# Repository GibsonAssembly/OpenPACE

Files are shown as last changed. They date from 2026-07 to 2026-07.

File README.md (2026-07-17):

# OpenPACE

Code, STL and Gerber files for EvoFlow and EvoSampler, together with the companion software repositories included as submodules.

## Repository layout

| Path | Contents |
|---|---|
| `EvoFlow` | EvoFlow reactor — STL and Gerber files |
| `EvoSampler` | EvoSampler — code, STL and Gerber files |
| `EvoMonitor` | Real-time monitoring dashboard (EvoHub appliance) — submodule of [Schwank-Lab/evoflow-monitor](https://github.com/Schwank-Lab/evoflow-monitor) |
| `EvoGenotype` | PACE genotype-trajectory analysis CLI — submodule of [Schwank-Lab/evo-genotype](https://github.com/Schwank-Lab/evo-genotype) |
| `Evotool` | Reactor control tool (`evotool.py`) and Pico controller firmware — submodule of [Schwank-Lab/evoflow-reactor](https://github.com/Schwank-Lab/evoflow-reactor) |

## Cloning

`EvoMonitor`, `EvoGenotype` and `Evotool` are git submodules, so clone recursively:

```bash
git clone --recursive https://github.com/GibsonAssembly/OpenPACE.git
```

If you already cloned without `--recursive`, initialise them with:

```bash
git submodule update --init --recursive
```

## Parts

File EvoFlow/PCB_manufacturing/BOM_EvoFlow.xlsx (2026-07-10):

Comment | Description | Designator | Footprint | LibRef | Quantity
LTC1050CS8#TRPBF,C580346 | Ampilfier | AMP1, AMP2 | SOIC127P599X175-8N | LTC1050CS8#TRPBF | 2
VT1E101M0607, C141426 | Capacitor Polarised,100uF, | C1, C2, C3, C4, C5, C6 | CAPAE660X800N | VT1E101M0607 | 6
22µF 25V 0805, C45783 | Capacitor 22µF +/-20% 25V 0805, C45783 | C7, C12 | C0805 | C22uF | 2
4.7uF, C162420 | Chip Capacitor, 4.7 µF,50V | C8, C9, C11, C13, C14, C19, C20, C22, C37, C39 | C0805 | C4.7uF | 10
C15850 | Chip Capacitor, 10uF, 25V, 0805, Thickness 1.45 mm | C10, C17, C18, C29, C30, C33, C34 | C0805 | C10uF | 7
100nF,C307331 | Chip Capacitor, 0402, CL05B104KB54PNC | C15, C16, C27, C28, C31, C32 | RESC1005X55N | C100nF | 6
100nF,C49678 | Chip Capacitor | C21, C23, C25, C26, C35, C36, C38, C40 | C0805 | C100nF | 8
22nF,50V, C1729 | Chip Capacitor | C24, C41, C42 | C0805 | C22nF | 3
S1A, C330217 | Diode, C330217 | D1, D2, D3, D4, D5, D6, D7, D8 | DIOM5026X262N | S1A+ | 8
FAN3224TMX | Gate driver, two channels, low side,C457631 | Driver1, Driver2, Driver3, Driver4, Driver5, Driver6, Driver7 | SOIC127P599X175-8N | FAN3224TMX | 7
RASPBERRY_PI_PICO_W, C7203003 | Raspberry Pie | IC1 | RASPBERRYPIPICOW | RASPBERRY_PI_PICO_W | 1
TMC2208-LA-T | C115944 | IC2, IC3, IC4 | QFN50P500X500X90-29N-D | TMC2208-LA-T | 3
LTE-5208A, No BOM | LED | IR1, IR2 | LTE5208A | LTE-5208A | 2
B2B-XH-A_LF__SN_ | Connector,C158012 | J1, J2, J3, J4, J5, J6, J7, J8 | SHDR2W64P0X250_1X2_740X575X700P | B2B-XH-A_LF__SN_ | 8
B4B-PH-K-S_LF__SN_, C131334 | Connector,C131334 | J9, J10, J11 | SHDR4W50P0X200_1X4_990X450X600P | B4B-PH-K-S_LF__SN_ | 3
LED, C2288 | Blue LED | LED1, LED2, LED3, LED4 | LEDM168X65N | LED | 4
DMN2053UVT-7 | MOSFET (N-Channel),C5248847 | MOS1, MOS2, MOS3, MOS4, MOS5, MOS6, MOS7 | SOT95P280X100-6N | DMN2053UVT-7 | 7
DC-005 2.0 | Connector,C16214 | P1 | DC005 | DC-005 2.0 | 1
IR photodiode, No BOM | Infra red photodiode, LTR-323DB , 2-Pin THD | PD1, PD2 | LTE5208A | Photodiode | 2
LD1117-5.0 | C347230, Fixed voltage regulator, 12V to 5V | PS1 | SOT230P700X190-4N | LD1117-5.0 | 1
C60816, RC0805FR-074K7L | Resistor, 4.7 kOhm | R1, R2, R3 | RESC2012X60N | RC0805FR-074K7L | 3
No BOM | Heater, No BOM | R4, R5, R6, R7, R8, R9 | TO508P305X812X1398-2P | MP915-200-1% | 6
Resistors,0603,360 Ohm | Resistor，C25194 | R10, R11, R12, R13 | RESC1608X55N | R360 | 4
Chip Resistors, 20k | C4184 | R14, R17, R20, R23, R24, R29, R30, R31, R32 | RESC1608X55N | R20k | 9
C17414, Resistor 10k, 0805 | Chip Resistor, 10 kOhm | R18, R19 | RESC2012X60N | R10k | 2
Resistors,0603,150 Ohm, C22808 | Resistor， C22808 | R21, R22 | RESC1608X55N | R150 | 2
K2-1102SP-C4SC-04 | Switch, C127509 | S1, S2, S3, S4, S5, S9, S10 | K2-1102SP-C4SC-04 | K2-1102SP-C4SC-04 | 7
C54949, DSIC02LSGET | 2 channel Switch | S6, S7, S8 | SOP254P930X445-4N | DSIC02LSGET | 3
DS18B20+,No BOM | Integrated Circuit, No BOM | TM1, TM2, TM3 | DS18B20 | DS18B20+ | 3
TC33X-2-203E | Variable Resistor，C720648 | VR1, VR2, VR3 | TC33X2503E | TC33X-2-203E | 3

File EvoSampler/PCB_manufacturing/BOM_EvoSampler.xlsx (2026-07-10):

No. | Quantity | Comment | Designator | Footprint | Value | Manufacturer Part | Manufacturer | Supplier Part | Supplier
1 | 3 | 100uF | C1,C2,C3 | CAP-SMD_BD6.3-L6.6-W6.6-LS7.6-FD |  | RVT1V101M0607 | ROQANG(容强) | C72478 | LCSC
2 | 1 | 680uF | C19 | CAP-SMD_BD10.0-L10.3-W10.3-LS11.3-FD-1 |  | RVT1E681M1010 | DMBJ(振宝佳) | C976031 | LCSC
3 | 1 | 220uF | C20 | CAP-SMD_BD10.0-L10.3-W10.3-LS11.3-FD |  | UWT1H221MNL1GS | Nichicon(尼吉康) | C125977 | LCSC
4 | 1 | 330uF | C30 | CAP-TH_BD8.0-P3.50-D0.6-FD |  | RC035M331LO8*14TH-2A1E | BERYL(绿宝石) | C357626 | LCSC
5 | 3 | B4B-PH-K-S(LF)(SN) | CN1,CN3,CN9 | CONN-TH_B4B-PH-K-S |  | B4B-PH-K-S(LF)(SN) | JST | C131334 | LCSC
6 | 3 | XH-3A | CN4,CN5,CN7 | CONN-TH_XH-3A |  | XH-3A | BOOMELE(博穆精密) | C2316 | LCSC
7 | 1 | ZX-XH2.54 | CN6 | CONN-TH_2P-P2.50_HX25003-2A |  | ZX-XH2.54-2PZZ | Megastar(兆星) | C7429632 | LCSC
8 | 1 | SS34 | D1 | SMA_L4.4-W2.8-LS5.4-RD |  | SS34 | Bourne Semicon (Shenzhen) | C266553 | LCSC
9 | 1 | 1N4007 | D2 | SMA_L4.3-W2.5-LS5.0-RD |  | 1N4007 | TWGMC(台湾迪嘉) | C727081 | LCSC
10 | 1 | DC-005 5.5-2.0MM | DC1 | DC-IN-TH_DC-5520-1 |  | DC-005 2.0 | BOOMELE(博穆精密) | C16214 | LCSC
11 | 1 | 33uH | L1 | IND-SMD_L5.0-W5.0_FNR5012S |  | CKCS5040-33uH/M | CENKER | C354612 | LCSC
12 | 1 | IRF520NS | Q1 | TO-263-2_L10.1-W9.1-P5.08-LS15.2-BR |  | IRF520NS-VB | VBsemi(微碧半导体) | C725067 | LCSC
13 | 3 | 2N7002_R1_00001 | Q2,Q3,Q4 | SOT-23-3_L2.9-W1.3-P1.90-LS2.4-BR |  | 2N7002_R1_00001 | PANJIT(强茂) | C282260 | LCSC
14 | 1 | 1kΩ | R13 | R0603 |  | RC0603FR-071KL | YAGEO(国巨) | C22548 | LCSC
15 | 6 | 10kΩ | R20,R21,R22,R23,R24,R25 | R0603 |  | RC0603FR-0710KL | YAGEO(国巨) | C98220 | LCSC
16 | 3 | K2-6639SP-S4SC-04 | SW1,SW2,SW3 | KEY-SMD_4P_K2-6639SP-R4SC-04 |  | K2-6639SP-S4SC-04 | 韩国韩荣 | C223738 | LCSC
17 | 3 | TMC2208 | U1,U2,U3 | HDR-TH_8P-P2.54-V-F-1
18 | 1 | LM2596S-5.0/TR | U4 | TO-263-5_L10.2-W8.6-P1.70-LS14.4-TL |  | LM2596S-5.0/TR | HGSEMI | C194349 | LCSC
19 | 1 | PICO W | U7 | LCC-40_L51.0-W21.0-P2.54-BL_RP2040-BASED |  | PICO W | Raspberry Pi(树莓派) | C7203003 | LCSC
20 | 6 |  | H1,H2,H3,H4,H5,H6 | HDR-TH_8P-P2.54-V-F-1 |  | 2.54-1*8P母环保 | BOOMELE(博穆精密) | C27438 | LCSC

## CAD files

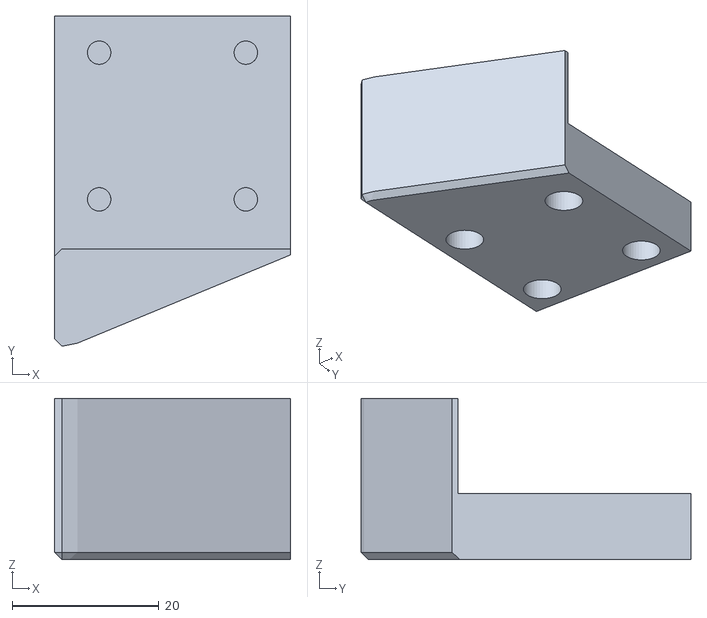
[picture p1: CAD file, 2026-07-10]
EvoFlow/3Dprintable_parts/STLs/10_syringe_piston_pusher.stl
32.2 x 45.0 x 22.0

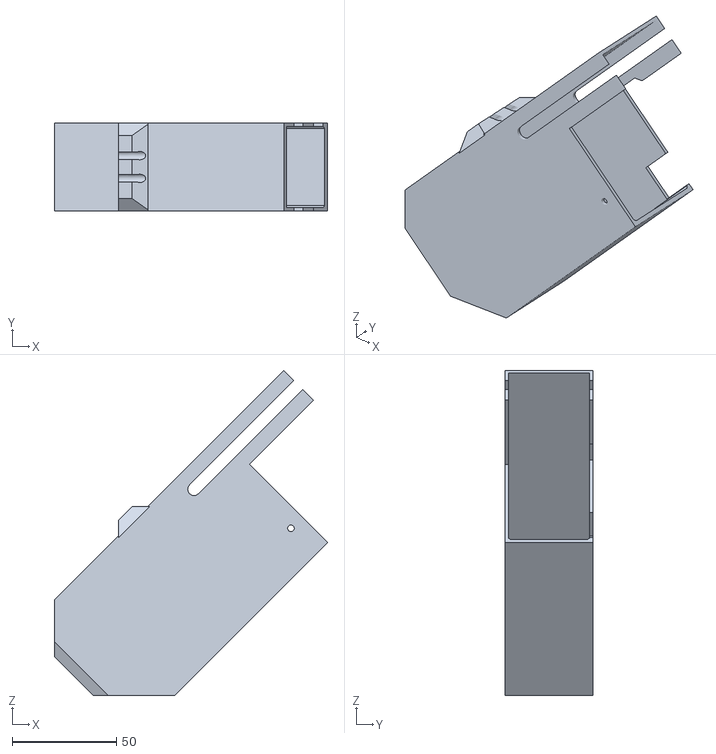
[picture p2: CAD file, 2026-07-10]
EvoSampler/3Dprintable_parts/STLs/08_Z_axis_cover.stl
131.0 x 42.1 x 155.8

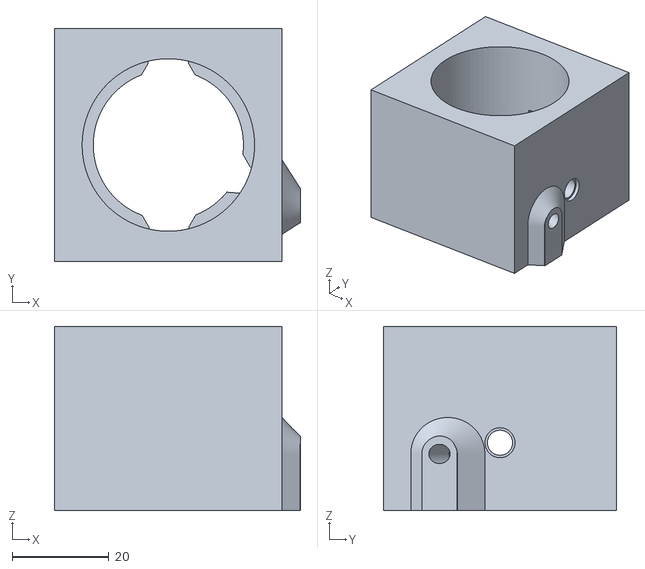
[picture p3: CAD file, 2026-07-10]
EvoFlow/3Dprintable_parts/STLs/04_EvoFlow_bioreactor_holder.stl
50.8 x 48.0 x 38.0

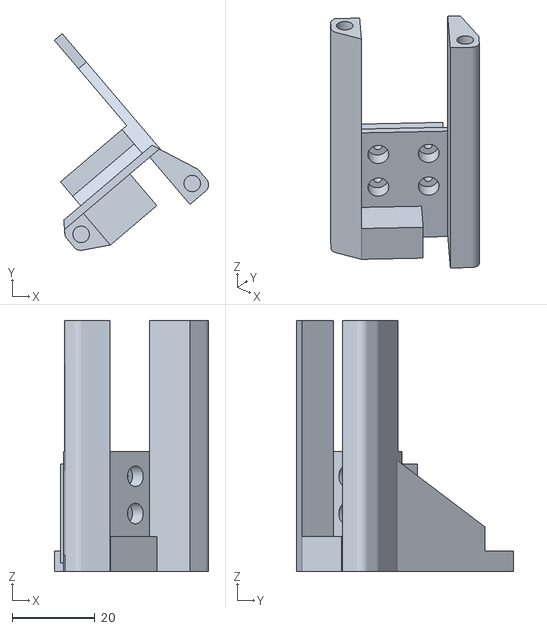
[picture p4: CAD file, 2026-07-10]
EvoSampler/3Dprintable_parts/STLs/09_Solenoid_holder.stl
37.3 x 52.3 x 60.6

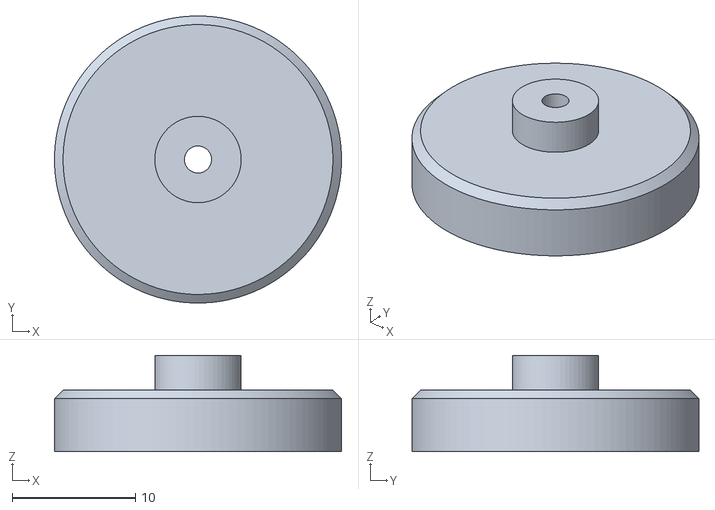
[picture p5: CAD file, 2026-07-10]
EvoFlow/3Dprintable_parts/STLs/07_Magnet_holder_L.stl
23.2 x 23.2 x 7.80

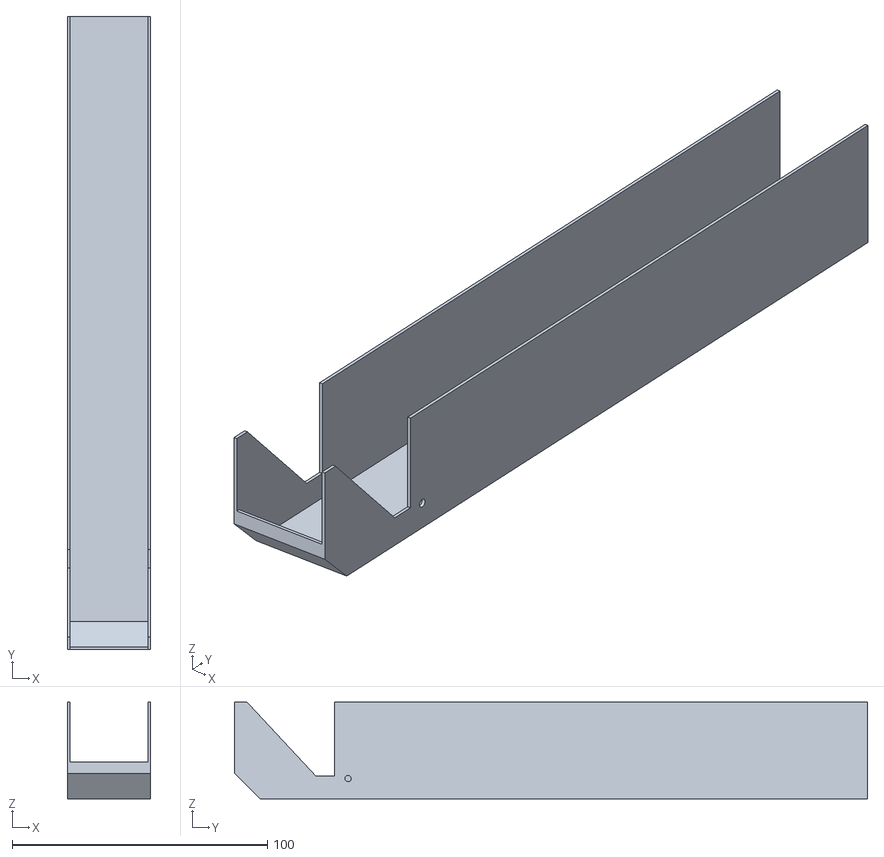
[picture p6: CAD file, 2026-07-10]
EvoSampler/3Dprintable_parts/STLs/06_X_axis_cover.stl
32.4 x 248.0 x 38.0

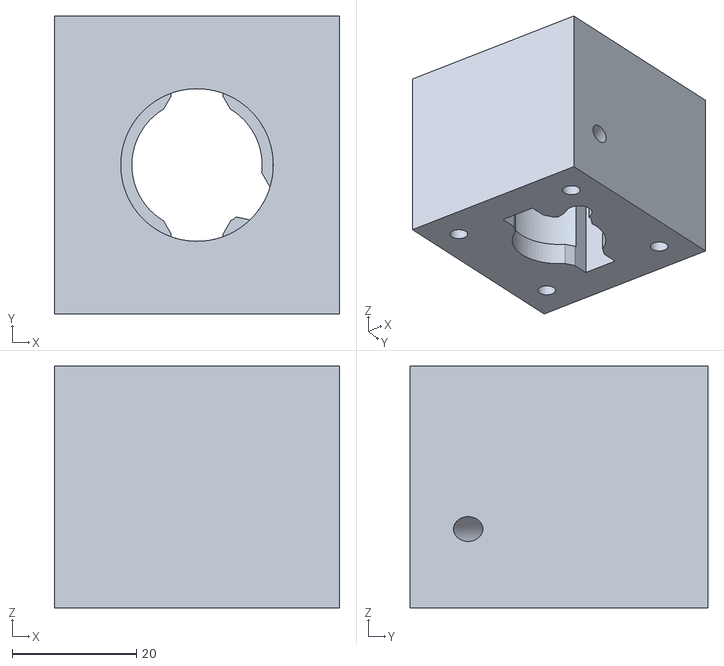
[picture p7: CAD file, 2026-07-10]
EvoFlow/3Dprintable_parts/STLs/05_EvoFlow_lagoon_holder.stl
45.9 x 48.0 x 39.0

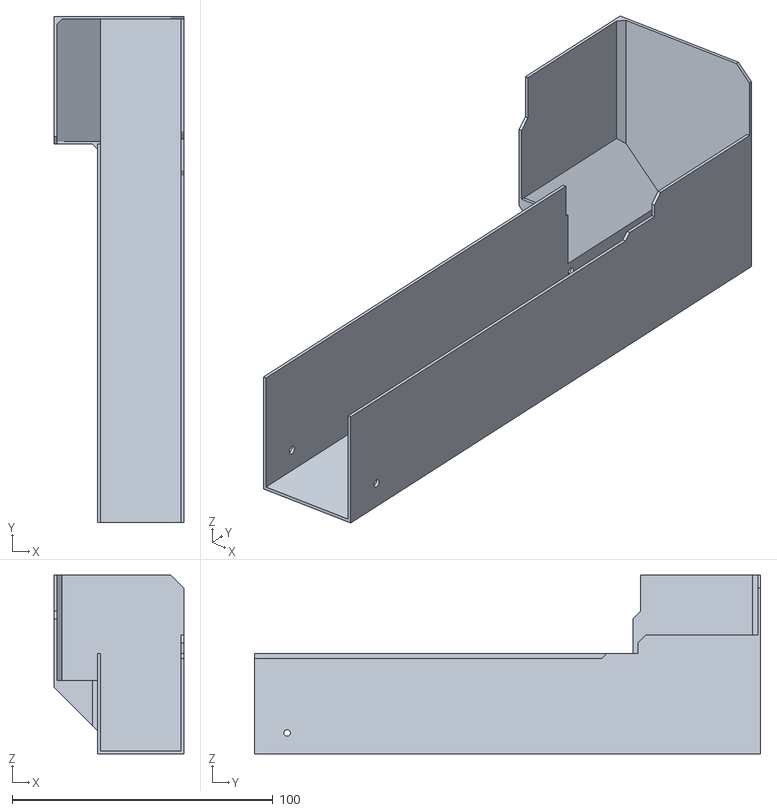
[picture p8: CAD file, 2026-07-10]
EvoSampler/3Dprintable_parts/STLs/07_Y_axis_cover.stl
49.7 x 194.0 x 68.5

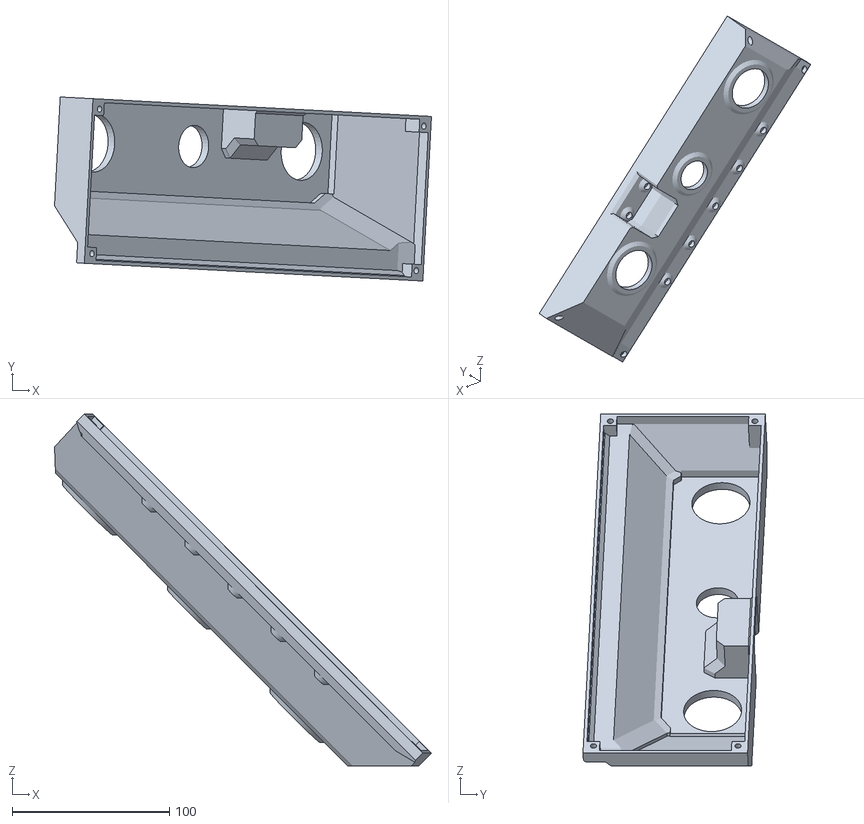
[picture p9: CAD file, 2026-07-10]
EvoFlow/3Dprintable_parts/STLs/02_Housing_cover.stl
239.7 x 117.0 x 223.7

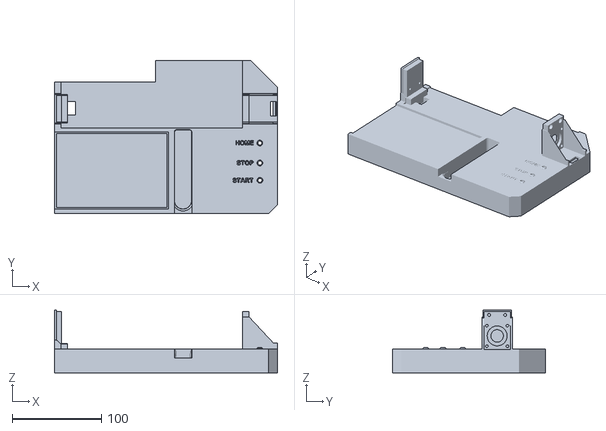
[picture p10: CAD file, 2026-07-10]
EvoSampler/3Dprintable_parts/STLs/01_EvoSampler_base.stl
250.0 x 171.8 x 70.6

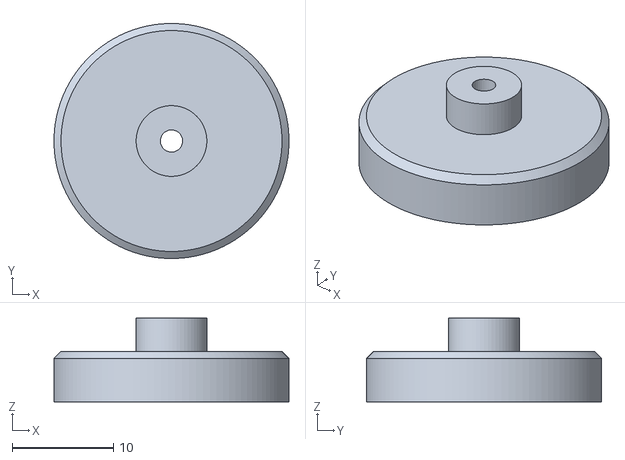
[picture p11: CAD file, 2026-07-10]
EvoFlow/3Dprintable_parts/STLs/06_Magnet_holder_B.stl
23.2 x 23.2 x 8.30

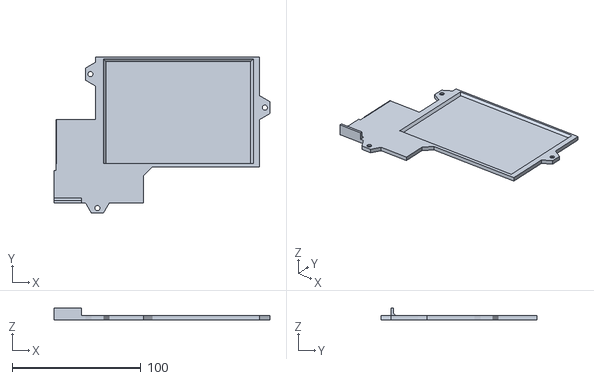
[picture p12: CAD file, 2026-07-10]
EvoSampler/3Dprintable_parts/STLs/05_EvoSampler_lid.stl
167.7 x 121.5 x 9.30

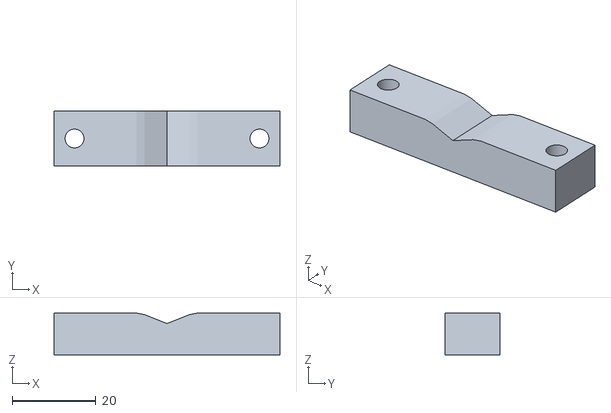
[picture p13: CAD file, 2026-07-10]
EvoFlow/3Dprintable_parts/STLs/12_Syringe_fastener.stl
54.0 x 13.2 x 10.0

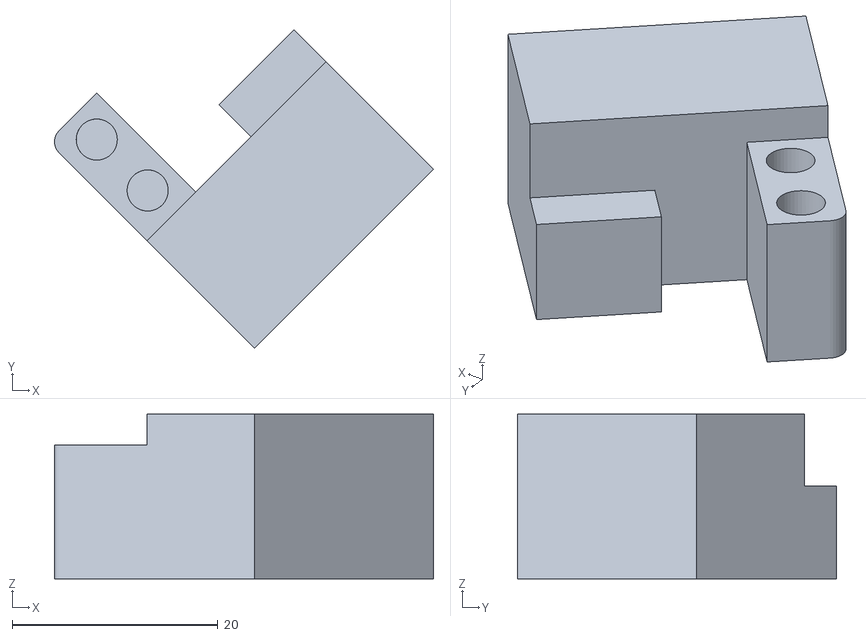
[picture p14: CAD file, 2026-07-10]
EvoSampler/3Dprintable_parts/STLs/04_Z_axis_limit.stl
36.9 x 31.0 x 16.0

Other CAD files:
EvoFlow/3Dprintable_parts/STLs/09_Lagoon_stirrer.stl
EvoSampler/3Dprintable_parts/STLs/02_Y_axis_holder.stl
EvoFlow/3Dprintable_parts/STLs/03_Button.stl
EvoSampler/3Dprintable_parts/STLs/03_Z_axis_holder.stl
EvoFlow/3Dprintable_parts/STLs/01_EvoFlow_housing.stl
EvoFlow/3Dprintable_parts/STLs/08_Bioreactor_stirrer.stl
EvoFlow/3Dprintable_parts/STLs/11_Syringe_pump_cover.stl

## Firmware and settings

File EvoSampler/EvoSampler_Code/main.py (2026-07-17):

from machine import Pin, PWM, Timer
from picozero import Button
import utime

#Axis Limit: X, Y, Z=50

#---------------------------------------------------------------------------------------------

# Define the sampling parameters
sampling_duration = 2  # Time to remain at each well for sampling in Minutes (max ~30ml/h --> 4 minutes)
sampling_timer_interval = 60  # Interval between samplings in Minutes

position_A1 = [6, 30] # Define the XY-coordinates of well A1 (top-left corner) in mm [x_mm, y_mm]
well_spacing_mm = 9 # Define the distance between wells of well-plate
num_rows = 8 # Define the number of rows in the plate
num_cols = 12 # Define the number of columns in the plate 
park_position = [140, 30, 0]  # Define the park position, where head is parked in between samplings in mm [x_mm, y_mm, z_mm]

#---------------------------------------------------------------------------------------------

sampling_duration = sampling_duration*1000*60 ## convert to milliseconds
sampling_timer_interval = sampling_timer_interval*1000*60 ## convert to milliseconds

sampling_started = False
# Define the 3 buttons for inputs

Button_Left = Pin(6, Pin.IN, Pin.PULL_UP)
Button_Mid = Pin(4, Pin.IN, Pin.PULL_UP)
Button_Right = Pin(5, Pin.IN, Pin.PULL_UP)

# Define pins for direction, step, enable, and limit switches
ydir = Pin(10, Pin.OUT)
zdir = Pin(13, Pin.OUT)
xdir = Pin(7, Pin.OUT)

ystep_pwm = Pin(11, Pin.OUT)
zstep_pwm = Pin(14, Pin.OUT)
xstep_pwm = Pin(8, Pin.OUT)

yenable = Pin(12, Pin.OUT)
zenable = Pin(15, Pin.OUT)
xenable = Pin(9, Pin.OUT)

xstop = Pin(27, Pin.IN, Pin.PULL_UP)
ystop = Pin(26, Pin.IN, Pin.PULL_UP)
zstop = Pin(22, Pin.IN, Pin.PULL_UP)

step_pins = [xstep_pwm, ystep_pwm, zstep_pwm]
dir_pins = [xdir, ydir, zdir]
enable_pins = [xenable, yenable, zenable]
limit_switches = [xstop, ystop, zstop]

# Define the solenoid trigger pin
solenoid_trigger = Pin(3, Pin.OUT)  # Adjust the pin number as needed
solenoid_trigger.value(0)  # Set solenoid to inactive state (assuming active-low)
solenoid_timer = Timer(-1) ## # Define the timer as software timer

## Set Microstepps:
MS1_1 = Pin(16, Pin.OUT)
MS2_1 = Pin(17, Pin.OUT)

MS1_2 = Pin(18, Pin.OUT)
MS2_2 = Pin(19, Pin.OUT)

MS1_3 = Pin(20, Pin.OUT)
MS2_3 = Pin(21, Pin.OUT)

MS1_1.value(0)
MS2_1.value(0)

MS1_2.value(0)
MS2_2.value(0)

MS1_3.value(0)
MS2_3.value(0)

# Define homing directions for each axis (1 for positive direction, 0 for negative direction)
homing_directions = [1, 0, 0]  # Adjust these values based on your setup
# Set inversion flags for axes: True means “invert the commanded direction”
invert_axis = [True, False, False]  # Invert X, leave Y and Z as is ## in case an axis does not go to the correct direction.
# Define steps per millimeter for each axis
steps_per_mm = 800  # 200 steps per rotation * 8 microsteps / 2 mm per rotation
# Define maximum speed in mm/s
max_speed_mm_per_s = 50  # Adjust this value as needed
# Calculate minimum delay between steps (in microseconds) for the maximum speed
min_delay_us = int(1e6 / (max_speed_mm_per_s * steps_per_mm))
# Define maximum delay for acceleration and deceleration phases
max_delay_us = 1000  # This can be adjusted based on desired acceleration profile
# Global position tracker in steps
current_position_steps = [0, 0, 0]  # Assuming the home position is 0,0,0 steps
# Enable all motors
for enable in enable_pins:
    enable.value(0)

# Initialize well counter
current_well_index = 0

# List of wells (96 in total)
wells = [(row, col) for row in range(num_rows) for col in range(num_cols)]

def configure_pwm(pwm, frequency):
    pwm.freq(frequency)
    pwm.duty_u16(32768)  # 50% duty cycle

def disable_pwm(pwm):
    pwm.duty_u16(0)

def step_one(axis, delay_us=100):  # Adjust delay_us to match your motor and driver requirements
    step_pins[axis].high()  # Set PWM to high
    utime.sleep_us(delay_us)
    step_pins[axis].low()  # Set PWM to low
    utime.sleep_us(delay_us)

def home_axis(axis, homing_direction, initial_speed=100, final_speed=250):
    dir_pins[axis].value(homing_direction)  # Set direction towards the limit switch
    enable_pins[axis].value(0)  # Enable the axis prior to homing
    while limit_switches[axis].value() == 1:
        step_one(axis, delay_us=initial_speed)
    dir_pins[axis].value(not homing_direction)  # Move back a bit
    for _ in range(4000):
        step_one(axis, delay_us=initial_speed)
    dir_pins[axis].value(homing_direction)  # Re-home slowly
    while limit_switches[axis].value() == 1:
        step_one(axis, delay_us=final_speed)
    enable_pins[axis].value(1)  # Disable the axis after homing

def home_all(homing_directions):
    home_axis(2, homing_directions[2], initial_speed=100, final_speed=250)  # Home Z-axis first with increased speed
    for axis in [0, 1]:  # Home X and Y axes simultaneously
        home_axis(axis, homing_directions[axis], initial_speed=100, final_speed=250)

def move_axes(steps, directions):
    global current_position_steps
    max_steps = max(steps)

    # Set directions and enable each axis
    for axis in range(3):
        # If this axis is inverted, flip the commanded direction.
        commanded_direction = directions[axis]
        if invert_axis[axis]:
            commanded_direction = 0 if directions[axis] == 1 else 1
        dir_pins[axis].value(commanded_direction)
        enable_pins[axis].value(0)

    # Execute the stepping loop.
    for current_step in range(max_steps):
        for axis in range(3):
            if current_step < steps[axis]:
                step_one(axis)

    # Disable axes and update current_position_steps based on the actual move
    for axis in range(3):
        enable_pins[axis].value(1)
        # For inverted axes, reverse the update relative to the computed direction.
        if invert_axis[axis]:
            if directions[axis] == 1:
                # Although the computed direction was “positive,” we sent the opposite command,
                # so the actual physical move is to the right.
                current_position_steps[axis] += steps[axis]
            else:
                current_position_steps[axis] -= steps[axis]
        else:
            if directions[axis] == 1:
                current_position_steps[axis] += steps[axis]
            else:
                current_position_steps[axis] -= steps[axis]

def move_to_position(target_mm):
    global current_position_steps
    # Convert target positions from mm to steps
    target_steps = [int(target_mm[i] * steps_per_mm) for i in range(3)]
    print(f"Moving to positions: {target_mm} mm, which corresponds to {target_steps} steps")

    # Calculate the number of steps to move and directions
    steps_to_move = [abs(target_steps[axis] - current_position_steps[axis]) for axis in range(3)]
    directions = [1 if target_steps[axis] > current_position_steps[axis] else 0 for axis in range(3)]

    # Set directions and enable each axis
    for axis in range(3):
        dir_pins[axis].value(directions[axis])
        enable_pins[axis].value(0)  # Ensure the axis is enabled

    # Move the axes simultaneously
    move_axes(steps_to_move, directions)
    
    print(f"Current position (steps): {current_position_steps}")

# Function to move to a specific well position
def move_to_well(row, col, position_A1):
    """
    Move to the specified well position in the grid.
    
    Parameters:
    - row: Row index (0-7 for A-H)
    - col: Column index (0-11 for 1-12)
    - position_A1: Coordinates of well A1 as (x_mm, y_mm)
    """
    # Calculate the target position relative to A1
    target_x_mm = position_A1[0] + col * well_spacing_mm
    target_y_mm = position_A1[1] + row * well_spacing_mm

    # Move to the target position
    move_to_position([target_x_mm, target_y_mm, current_position_steps[2] / steps_per_mm])  # Z remains unchanged

def move_z_axis(distance_mm, direction):
    """
    Move the Z-axis by a specified distance.

    Parameters:
    - distance_mm: Distance to move in millimeters.
    - direction: Direction to move (0 for down, 1 for up).
    """
    # Calculate the number of steps required for the distance
    steps = int(distance_mm * steps_per_mm)
    
    # Set the direction
    dir_pins[2].value(direction)
    
    # Enable the Z-axis motor (if needed)
    enable_pins[2].value(0)
    
    # Move the Z-axis by the calculated number of steps
    for _ in range(steps):
        step_one(2, delay_us=200)
    
    # Optionally disable the Z-axis motor after movement
    enable_pins[2].value(1)

# Example usage to move Z-axis up and down by 40 mm
#move_z_axis(40, 1)  # Move up by 40 mm
#utime.sleep(1)      # Optional pause between movements
#move_z_axis(40, 0)  # Move down by 40 mm

# Function to trigger the solenoid
def trigger_solenoid(timer):
    global current_well_index
    sampling_running = False ## ensure that this function can only be called once
    # Check if all wells have been sampled
    if current_well_index >= len(wells):
        solenoid_timer.deinit()  # Stop the timer
        return

    # Calculate the current well's row and column by row-first order
    row = current_well_index % num_rows
    col = current_well_index // num_rows

    # Move to the current well
    move_to_well(row, col, position_A1)
    move_z_axis(18, 1) ## move into well
    # Trigger solenoid
    solenoid_trigger.value(1)  # Activate solenoid
    utime.sleep_ms(sampling_duration)  # Keep the solenoid activated for sampling_duration
    solenoid_trigger.value(0)  # Deactivate solenoid
    
    move_z_axis(32, 0) ## move out of well
    
    # Increment well index
    current_well_index += 1

    # Move back to park position
    move_to_position(park_position)
    
def start_sampling():
    global sampling_started
    if not sampling_started:
        print("Starting sampling...")
        sampling_started = True
        trigger_solenoid(None)  # Immediately trigger the first sample
        solenoid_timer.init(period=sampling_timer_interval, mode=Timer.PERIODIC, callback=trigger_solenoid)
        
def handle_button_press(pin):
    press_time = utime.ticks_ms()
    while not Button_Left.value():
        if utime.ticks_diff(utime.ticks_ms(), press_time) >= 2000:
            start_sampling()
            break
        
def stop_and_home():
    global sampling_started
    if sampling_started:
        print("Stopping operations and homing axes...")
        solenoid_timer.deinit()  # Stop the sampling timer
        sampling_started = False
        home_all(homing_directions)  # Home all axes

def handle_stop_button_press(pin):
    press_time = utime.ticks_ms()
    while not Button_Right.value():
        if utime.ticks_diff(utime.ticks_ms(), press_time) >= 2000:
            stop_and_home()
            break
        



home_all(homing_directions) ## Start with homing
Button_Left.irq(trigger=Pin.IRQ_FALLING, handler=handle_button_press)
#solenoid_timer.init(period=sampling_timer_interval, mode=Timer.PERIODIC, callback=trigger_solenoid)
Button_Right.irq(trigger=Pin.IRQ_FALLING, handler=handle_stop_button_press)

#while True:
#    pass

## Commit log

2026-07-16 Add EvoMonitor, EvoGenotype, and Evotool as submodules
    - EvoMonitor -> Schwank-Lab/evoflow-monitor
    - EvoGenotype -> Schwank-Lab/evo-genotype
    - Evotool -> Schwank-Lab/evoflow-reactor (evotool + pico controller code)
2026-07-16 Switch submodule URLs to HTTPS and document layout in README
    Repos will be public, so use HTTPS so the submodules can be cloned
    anonymously (git clone --recursive). Add a repository-layout table and
    cloning instructions to the README.
2026-09-22 Update submodule pins and add CITATION.cff for the Zenodo deposit
    The pinned Evotool and EvoMonitor commits predated the git@ -> https URL
    change merged in July, so an anonymous reader cloning the archived snapshot
    could not run `poetry install`. Repoint all three submodules at their current
    default-branch heads, which also carry the newly added MIT license files.
    CITATION.cff gives the repository a "Cite this repository" entry on GitHub
    and records the protocol paper as the preferred citation. The Zenodo concept
    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
2026-10-15 Update Evotool and EvoMonitor pins; add Xiang Liu and Daniel Razansky
    Evotool moves to evoflow-reactor master (ebae534) and EvoMonitor to
    evoflow-monitor main (d6a9118): the EvoHub/EvoBridge appliance, the release
    images, and Evotool reaching the hub via EVOHUB_HOST, as described in the
    protocol. CITATION.cff gains the two PCB co-authors, matching the paper.
2026-10-15 Update Evotool pin to evoflow-reactor master with the EVOHUB_HOST .env
